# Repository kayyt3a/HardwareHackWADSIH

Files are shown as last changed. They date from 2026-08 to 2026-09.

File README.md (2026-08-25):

# Vocalens — FourSight

Hardware Hack 2026 — Challenge 1C, "Eyes for Labels"

A pair of glasses for people with low vision that read the world aloud on
request. Say the wake word and ask a question — "what does this say?",
"what colour is this?", "is this the ten or the twenty?" — and hear a short
spoken answer through a bone-conduction transducer.

Also handles:
- **Barcode/QR scanning** — checked first, before the vision model, so a
  recognised product answers near-instantly with no model call at all.
- **A per-wearer profile** (`server/profile_store.py`, set up once at
  `/setup`) — either dosage-relevant facts (age, weight, conditions,
  allergies) surfaced as context when relevant, or a voice-built reminders
  list ("remember this" / "what do I have coming up"). See
  `docs/ARCHITECTURE.md` for why these are kept as facts-only context, never
  a recommendation.

Built on a Seeed XIAO ESP32S3 Sense as a dumb sensor/actuator (camera, onboard
mic, a temple touch pad as a manual backup trigger, a bone-conduction
transducer for audio out). All intelligence lives server-side in Python,
following the same capture → server → vision-language model → action pattern
as [otto_finder](https://github.com/bethqzak/otto_finder).

## Why glasses, not handheld

Elderly users are prone to losing or forgetting to carry a separate handheld
device. Worn glasses solve that by design — nothing to remember to pick up —
and pointing your face at something is also a more natural aiming motion than
aiming a handheld unit, which directly addresses the brief's repeated point
that "aiming, not reading, is the real problem."

## Activation

Two triggers, by design (see `docs/ARCHITECTURE.md` for the reasoning):
- **Wake word** ("hey ..., what does this say?") — hands-free, the headline
  UX. Runs as local on-device keyword spotting so no audio leaves the glasses
  until it fires.
- **Touch pad on the temple** — manual backup for noisy environments or a
  wake-word miss, and what to build/test against first since the wake-word
  path depends on ESP-SR integration (see `firmware/src/wake_word.h`).

## Why a dedicated device and not just a phone

- Hands-free and always worn — nothing to find, unlock, or hold up.
- Head-aim replaces screen-aim, which matters when you can't see the screen
  to aim it in the first place.
- Silent and camera-off by default: nothing records or transmits until a
  trigger fires — an important claim to be able to make plainly in the pitch
  given a face-worn camera reads as more surveillance-adjacent than a
  handheld one.

## Repo layout

```
firmware/   PlatformIO project for the XIAO ESP32S3 Sense
server/     FastAPI server: speech-to-text + vision call + TTS
docs/       Architecture notes, pitch prep, judging-criteria checklist
```

## Quick start

**Server**
```
cd server
python -m venv .venv && source .venv/bin/activate
pip install -r requirements.txt
cp .env.example .env   # fill in ANTHROPIC_API_KEY and OPENAI_API_KEY
uvicorn main:app --host 0.0.0.0 --port 8000
```

`pyzbar` (barcode decoding) needs the system `zbar` library — `apt install
libzbar0` on Debian/Ubuntu, `brew install zbar` on macOS — install that
before `pip install -r requirements.txt` if the import fails.

Visit `http://<server-ip>:8000/setup` to set up a wearer's profile
(dosage facts or reminders mode) before a demo.

**Firmware**
```
cd firmware
cp src/secrets.h.example src/secrets.h   # fill in WiFi + server IP
pio run -t upload
```

Bring-up order: get the touch-pad trigger + camera + `/read_label` round trip
working first (no mic, no wake word needed), then layer on mic recording +
`/ask`, then wake-word detection last — it's the highest-risk piece, see
`firmware/src/wake_word.h`.

See `docs/ARCHITECTURE.md` for the full data flow and `docs/JUDGING_CHECKLIST.md`
for how this addresses the brief's dignity/privacy/failure-mode questions.

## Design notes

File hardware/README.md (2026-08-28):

# Vocalens — enclosure

**Two pods, kit parts only, zero purchases.** No FPC ribbon, no
bone-conduction transducer — nothing bought. Bone conduction stays a
documented future upgrade (see below); the two-pod split itself is achieved
with the kit's own jumper wires instead.

## What it is

Two 3D-printed pods connected by jumper wires along the temple arm — sitting
**beside** the temple arm, not stacked on top of it (see "How they sit on
the arm" below for why that distinction matters):

- **Front pod** (near the hinge): the XIAO ESP32S3 Sense with its camera
  left attached — no ribbon surgery — plus the touch pad. 48 × 10 × 29mm
  (length along the arm × vertical × outward from the head).
- **Rear pod** (behind the ear): the kit's audio amplifier and speaker.
  57 × 10 × 38mm.

Connected by 5 jumper wires (BCLK, LRC, DIN, 3V3, GND) from the kit's own
stock (65 M-M + 20 F-F + 20 F-M) — I2S is a slow serial protocol, so it
tolerates that run length without the signal-integrity risk a stretched
camera ribbon would carry.

**Honest tradeoff:** the jumper wires run exposed along the outside of the
temple arm for ~10cm. Less tidy than a hidden ribbon, and worth naming
proactively in the pitch: "jumper wires for this prototype, a custom flex
cable in a production version."

Clipping onto an existing frame rather than fabricating one from scratch
avoids the hinge/nose-bridge/lens-fit problem entirely — mounting is the
thing the challenge brief calls out as most often underestimated, and a
frame that already fits a real face solves that for free.

## How they sit on the arm — the vertical dimension is the one that matters

Both pods are deliberately **thin vertically (10mm) and long outward
(29-38mm)**, not the other way around. This isn't cosmetic — it's the
difference between a pod that clears the head and one that doesn't.

A temple arm sits right against the side of the skull. There's almost no
clearance directly above or below it before you hit hair or bone; there's
plenty of clearance straight outward, away from the head. So every
component's **thickness** (a PCB's own profile, a speaker's depth — a few
mm) is what's allowed to add to the pod's vertical extent, and every
component's **footprint** (a 28mm speaker diameter, a 19mm board width) is
what extends outward instead. Get this backwards and the pod piles up on
top of the arm and presses into the wearer's head — which is exactly what
an earlier version of this file did (front pod was 22mm vertical, rear pod
was 31mm, both several times the arm's own ~6mm width).

The front pod's camera also no longer sits stacked on top of the board —
it's positioned beside it along the arm's length instead, using the slack
in its stock ribbon. That trade costs the front pod some length (36mm →
48mm) but is what gets its vertical extent down from 22mm to 10mm — worth
it, since length runs along a part of the head with actual room, and
vertical bulk runs straight into it.

## Files

- `cad/vocalens_pod.scad` — parametric source
- `cad/split_plate.stl` — the two-pod build: both pods, both lids, fit test
- `cad/frontboard_*.stl`, `cad/rearaudio_*.stl` — the same parts separately
- `cad/single_plate.stl` — a one-pod fallback, kept for reference. Still
  bulkier vertically (23mm) than the split build, since it has nowhere to
  lay the board+camera+amp side by side without becoming very long — prefer
  the split build whenever possible.

## Print order

**1. `fit_test.stl` first, always.** Cut from `split_plate.stl` or render
alone:
```
openscad -o fit_test.stl -D 'part="fit_test"' cad/vocalens_pod.scad
```
~3 minutes. Snap it onto your actual glasses.
- Won't go on / splays the arm → increase `SNAP_GAP`, reprint
- Slides around loosely → decrease `SNAP_GAP`, reprint
- Rattles in the channel → your `TEMPLE_THICKNESS`/`TEMPLE_WIDTH` don't
  match your real glasses — measure again

Only proceed once it grips properly.

**2. Then `split_plate.stl`** — both pods, both lids, a spare fit test,
113 × 48mm, comfortably inside the Snapmaker U1's 270 × 270mm bed.

### Slicer settings (Snapmaker U1, 0.4mm nozzle)

- Layer height 0.16mm
- 4 perimeters (`WALL` is 1.6mm, sized for exactly this)
- Print bases cavity-up, as modelled — the temple channel bridges rather
  than needing supports
- Both lids in `split_plate.stl` are pre-flipped rib-side-up so they sit
  flat on the bed with no supports; if slicing a lid alone, flip it yourself
- **Material: print bases in TPU, lids in PETG.** The base is the part
  that flexes every time the pod is clipped on/off — TPU doesn't fatigue or
  crack under repeated flex the way PLA/PETG do, and it's more forgiving of
  small errors in `SNAP_GAP`. The lid doesn't flex; it just needs to hold
  its shape, so keep it rigid (PETG). This needs no CAD changes — it's a
  per-part material choice, not a geometry change. TPU needs its own
  slicer profile (slower speed, less retraction) — test on a spare small
  part first if the U1 doesn't already have one dialled in.
- Use PLA only for the disposable `fit_test.stl` iterations while tuning
  `SNAP_GAP` — fastest to print, and you'll reprint it several times

## Measure before you print

Every dimension in `vocalens_pod.scad` is a **placeholder**. Real numbers,
off your actual parts:

| Parameter | Measure |
|---|---|
| `TEMPLE_THICKNESS`, `TEMPLE_WIDTH` | The glasses you're clipping onto |
| `CAM_LEN/WID/HGT` | The camera module, still attached to its ribbon |
| `XIAO_LEN/WID` | The board's footprint |
| `XIAO_THICK` | The board's own profile (PCB + tallest onboard part, e.g. the USB connector) **excluding** the camera — this is new, and is what lets the camera sit beside the board instead of stacked on it |
| `SPKR_DIA`, `SPKR_HGT` | The kit's round speaker |
| `AMP_LEN/WID/HGT` | The kit's Audio Converter & Amplifier module |

No separate touch sensor needed: ESP32 capacitive touch runs off a bare
GPIO pad. The touch pad is a small metal disc or screw head glued into the
lid's recess and wired back to one pin.

## For the pitch: what we'd build with more time/budget

Say this plainly and proactively — it reads as scoping discipline, not as
an apology, and it directly answers the brief's "what would you do next."

| Upgrade | What it needs | What it buys |
|---|---|---|
| **Camera fully detached from the board** (rather than riding along in the front pod) | A ~10cm FPC ribbon (the camera's kit ribbon is too short to reach the rear pod) | Front pod shrinks to a camera-only footprint, and its length drops back toward ~26mm since the board no longer shares the pod at all |
| **Tidy, hidden cabling** between pods | A short length of thin sheathed cable, or a printed channel | Replaces the exposed jumper wires with something that looks intentional |
| **Bone-conduction audio** | A transducer (not stocked in Perth; not in either kit) | Rear pod's outward extent drops sharply since the speaker's 28mm footprint is replaced by a ~21mm transducer mounted flush against the head rather than sitting inside the cavity; private to the wearer; ears stay open |
| **Wake-word activation** | Firmware only (ESP-SR), no purchase | Hands-free — no tap needed at all |

We deliberately built this prototype from the provided kit with no external
sourcing, so what you're looking at tonight has zero shipping risk and zero
budget beyond what the event gave every team. Pre-rendered reference STLs
for the bone-conduction variant are in `cad/bone_conduction/` if useful for
a visual in the deck — they were not printed for this build.

## Known limitations, stated plainly

- **Jumper wires run exposed** along ~10cm of the temple arm between the
  pods. Not hidden, not strain-relieved. Say this in the pitch rather than
  let a judge notice it first — it's the direct, honest cost of a two-pod
  split with zero external sourcing.
- Both pods extend noticeably outward from the head (29-38mm) in exchange
  for staying thin vertically. That's the deliberate trade this design
  makes — see "How they sit on the arm" above — but it does mean the pods
  are visible in profile from the side, more like a small camera clipped on
  than a flush-fitting accessory.
- Corners are lightly rounded (1mm) but the overall shape is still a
  utilitarian bar, not a finished consumer product.
- The clip grips by spring tension only, from the base material itself
  (TPU is the intended material for exactly this reason — see slicer
  settings above). If a PLA/PETG-printed base still feels loose in
  practice, reprinting the base in TPU is the real fix; there isn't
  meaningful room in the channel's tolerance to add a separate liner
  without resizing it.
- No strain relief where cables exit either pod.

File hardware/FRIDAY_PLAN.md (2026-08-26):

# Friday prototype — two-day plan

**Goal:** something you can put on your face, tap, and hear it read a label.
Nothing more.

**This is the committed build, not a stopgap.** The team has decided against
any external purchases — no bone-conduction transducer, no FPC ribbon.
Two pods, connected by the kit's own jumper wires instead of a ribbon: the
XIAO+camera up front, the amp+speaker behind the ear. Bone conduction and a
tidied/hidden cable stay a "what we'd build next" slide in the pitch (see
`hardware/README.md`).

**Files:** `cad/split_plate.stl` — both pods, both lids, fit test. That's
the whole print, for Friday and for the final demo.

**Fallback if printing time runs short:** `cad/single_plate.stl` — one pod,
everything in it, no jumper-wire run to route. Same electronics, same
firmware, just one enclosure instead of two. Switching to this costs you
nothing at the firmware/server level if Thursday goes badly.

**Honest expectations.** The wires between the pods run exposed along the
temple arm — not hidden, not strain-relieved. Say this plainly in the pitch
as the direct, stated cost of a two-pod split with zero external sourcing
— that's a deliberate scope decision, not an oversight, and framed that way
it reads as discipline rather than a limitation you're hiding.

---

## Split the work — 4 people, 2 tracks in parallel

Do NOT serialise this. Tracks A and B don't touch each other until Thursday
evening.

| Track | People | Job |
|---|---|---|
| **A — Electronics** | 2 | Get camera → server → speech working on the bench |
| **B — Enclosure** | 2 | Measure, print, test-fit |

---

## WEDNESDAY

### Track A — electronics (bench only, no enclosure)

1. **Flash the XIAO, confirm the camera works.** Use any stock ESP32 camera
   example first. If you don't get an image, stop and fix that — nothing
   downstream matters.
   - PSRAM must be set to **OPI PSRAM** in board config or camera init fails.
2. **Stand up the server.** `cd server && pip install -r requirements.txt`,
   fill in `.env`, `uvicorn main:app --host 0.0.0.0 --port 8000`.
   - `pyzbar` needs the system `zbar` library — `apt install libzbar0` /
     `brew install zbar`. Do this now, not Thursday night.
   - Test it with no hardware at all: POST a photo of a label from your
     laptop to `/read_label` with curl. Confirm you get audio back. **This
     de-risks the whole AI half before hardware is involved.**
3. **Wire the amp + speaker** (jumper wires, no soldering unless the speaker
   leads need it). Use SHORT wires on the bench for now — you'll swap to
   temple-length ones once both pods exist, on Thursday:

   | Amp | XIAO | |
   |---|---|---|
   | BCLK/SCK | GPIO 7 | |
   | LRC/WS | GPIO 8 | |
   | DIN | GPIO 9 | |
   | VIN | 3V3 | |
   | GND | GND | |

   Play any fixed sound from the XIAO. Don't involve the server yet.
4. **Join them up.** Tap-to-capture → server → speech out of the speaker.
   For the touch pad, a jumper wire from **GPIO 3** to a coin or screw head.

**End of Wednesday, Track A:** a breadboard rat's nest that takes a photo
when you touch a wire and speaks the answer. Ugly. Working.

### Track B — enclosure

1. **Measure everything** with callipers (ruler is OK):
   - Temple arm thickness and width of the glasses you're using
   - The XIAO with camera attached, and the amp module, and the speaker
2. **Update those numbers** at the top of `cad/vocalens_pod.scad`.
3. **Print `fit_test` only.** ~3 minutes. Snap it on the glasses.
   - Won't go on / splays the arm → increase `SNAP_GAP`, reprint
   - Slides around → decrease `SNAP_GAP`, reprint
   - Expect 2-3 iterations. This is normal and it is cheap.
4. Once the clip grips: re-render and print `split_plate.stl` (both pods).
   ```
   openscad -o split_plate.stl -D 'part="split_plate"' cad/vocalens_pod.scad
   ```
   Running behind schedule? Print `single_plate.stl` instead — one pod, no
   jumper-wire run between pods to fuss over. Decide this by end of
   Wednesday, not Thursday night.

**End of Wednesday, Track B:** a clip that grips your glasses properly, and
pod(s) printing overnight.

---

## THURSDAY

### Track B (morning)

5. **Dry-fit the electronics into the printed pod** — no glue yet. Does the
   board go in? Does the camera line up with the lens hole? Does the lid
   close?
   - Something doesn't fit → adjust that parameter, reprint that one part.
     You have all day. This is why you dry-fit before gluing.

### Track A (morning) — hardening, not new features

6. **Run the demo ten times in a row.** Count failures. You're looking for:
   - WiFi dropping or reconnecting slowly
   - Touch pad false-triggering or missing taps (tune `TOUCH_THRESHOLD`)
   - Server timeouts
7. **Fix whatever failed.** Do not add features today.

### Both tracks (afternoon)

8. **Assemble for real.**
   - Front pod: board (camera attached) glued in, lens aligned with the
     hole; touch-pad metal glued into the lid recess and wired; USB cable
     out through the side slot
   - Rear pod: amp and speaker seated side by side, speaker under the
     grille holes
   - Swap the bench's short jumper wires for temple-length ones between the
     pods, re-test before clipping anything on
   - Press both lids on, clip both pods to the temple arm, route the wires
     along the top edge with a dot of removable adhesive
9. **Wear it. Test it. Ten more times.**

---

## FRIDAY

10. **Morning: demo rehearsal, not building.** Run the three demo beats:
    - a barcode read (fast, no model call)
    - an open question ("what does this say?")
    - a deliberate bad angle → it says it can't see clearly
11. **Take photos and video of it working.** Do this while it works. If
    something breaks Friday afternoon you still have evidence.
12. **Write down what broke this week and what you'd do next.** That's your
    "what's next / what we didn't build" pitch slide, and it's much easier to
    write now than three weeks from now.

---

## If you fall behind — cut in this order

1. **Cut the spoken question first.** Tap-to-capture with a fixed "what does
   this say?" is a complete demo. `/read_label` already does exactly this and
   needs no mic work at all.
2. **Cut on-device audio second.** Play the server's reply from the laptop
   speakers. Say so plainly in the pitch — judges accept scoping honesty.
3. **Cut the enclosure last.** Electronics gaffer-taped to glasses still
   demonstrates the idea. A beautiful empty box does not.

**Never cut:** the confidence gate that makes it say "I can't see that
clearly." That behaviour is worth more to the judges than any feature —
it is a specific thing the brief says it scores.

---

## After Friday (the remaining 3 weeks)

No purchases — the enclosure and speaker are done as of this build. Focus
shifts entirely to hardening what's built and to firmware:

- Wake word (ESP-SR) — highest risk, keep the touch pad as backup regardless
- Round the enclosure edges; the brief judges whether it looks wearable
- Reliability passes: run the demo dozens of times, fix what fails
- Battery power instead of USB tether
- Rehearse the pitch's "what we'd build next" answer — two-pod split and
  bone conduction, from `hardware/README.md` — so it's ready when asked
- Battery, so it isn't USB-tethered

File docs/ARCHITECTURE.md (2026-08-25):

# Architecture

## Data flow

```
[XIAO ESP32S3 Sense, glasses-mounted]
   trigger: wake word (local, on-device) OR temple touch-pad tap
        |
        v
   record ~4s of question audio from onboard mic
   capture JPEG frame
        |
        v  HTTP POST multipart/form-data (image + question_audio)
[FastAPI server, LAN]
        |
        v  Whisper transcription of question_audio (if present)
        v  intent classification (keyword-based, server/intent.py):
        |    "remember" -> save current read to the profile's reminders
        |    "recall"   -> read back saved reminders, no camera/model call
        |    "ask"      -> default path, continues below
        v
   [ask path] barcode/QR decode first (server/barcode.py) -- if it decodes
   AND the product is found in Open Food Facts, answer immediately, no
   model call at all
        |  (no barcode, or not found -> fall through)
        v
   one Claude vision call: image + transcribed question + optional dosage
   context from the user's profile (age/weight/conditions/allergies --
   facts only, the prompt explicitly forbids the model from turning these
   into a safety verdict, see server/vision.py)
   prompt asks for: spoken_summary, category, confidence, needs_reposition
        |
        v  if confidence low or needs_reposition: skip the model's answer,
        |  return a short "can't see that clearly, move closer" message
        v
   TTS synthesis -> MP3 bytes
        |
        v  HTTP response: JSON header + streamed MP3 body
[XIAO ESP32S3 Sense]
   play MP3 over I2S -> amp -> bone-conduction transducer
```

## Why two triggers, not just the wake word

The wake word is the headline UX ("glued to their head," hands-free,
matches how the team wants this to feel to use) but it carries real
technical risk: on-device wake-word spotting (ESP-SR WakeNet) is the hardest
integration in this build, and a demo-night miss with no fallback would
strand the whole demo. The touch pad costs almost nothing to add and means
the rest of the pipeline (camera, mic, server, TTS, playback) can be built
and fully tested well before wake-word detection is working. Build in this
order:
1. Touch pad + camera + `/read_label` (no audio question at all)
2. Touch pad + mic + `/ask` (spoken question, still manually triggered)
3. Wake word replacing/joining the touch pad as the primary trigger

## Why one model call per question, not a pipeline

Same reasoning as otto_finder: doing interpretation + response-shaping in one
Claude vision call (given the transcribed question as context) is simpler to
reason about and cheaper to build in a hackathon timeframe than chaining
multiple models. Speech-to-text is a separate call because Claude's messages
API doesn't take raw audio input directly — Whisper handles that step, then
the transcribed text goes into the same vision call as before. (otto_finder
avoided this by using Gemini via OpenRouter, which accepts audio and image in
a single multimodal call — worth considering as a later optimisation if
reducing to one round-trip matters more than sticking with Anthropic's
vision credits; see `server/vision.py` for the swap point.)

## Latency budget

Trigger → spoken answer, target under ~5-6s (a bit more headroom than a
handheld device since there's a transcription step in the chain now):
- Mic recording: ~2-4s, fixed by how long the person takes to ask
- JPEG capture + WiFi upload: ~200-500ms on local WiFi at VGA resolution
- Whisper transcription: ~0.5-1.5s
- Claude vision call: ~1-3s (dominant network cost — keep the prompt short)
- TTS synthesis + playback start: ~0.5-1s, streamed so playback starts
  before the full file arrives

## Offline behaviour

If the server is unreachable, the firmware falls back to on-device
barcode/QR decode and speaks a locally-stored "no internet, can't look that
up right now" message rather than hanging silently. See
`firmware/src/offline_fallback.h`. Speech-to-text and TTS both need network
in the current config (OpenAI-backed), so the offline path skips the
question entirely rather than attempting a degraded version of it.

## User profile: dosage facts vs. reminders

`server/profile_store.py` holds one JSON record per wearer, set up once via
the bench-only form at `/setup` (see `server/static/profile_setup.html`) —
this is a setup tool, not part of the wearable's own interaction loop.

Two `profile_type` modes, matching the two personas discussed for this
build:
- **"dosage"** — age, weight, known conditions, known allergies. Only ever
  fed to the model as context to *surface* a printed detail the person
  might care about ("this contains X, which you've listed as an allergy").
  The system prompt explicitly forbids turning this into a recommendation
  or safety judgment — this device is not a medical device (see the
  brief's ethics section), and a dosage *verdict* is 1B's territory, not
  1C's.
- **"reminders"** — a plain list the wearer builds themselves by saying
  "remember this" after a read (e.g. pointing at an event flyer or
  appointment card). Recalled by asking "what do I have coming up" — pure
  text-to-speech from stored strings, no camera or model call needed for
  recall itself. This is deliberately NOT a synced calendar; it's exactly
  as much memory as the wearer explicitly asked the device to keep.

Only one profile type should be set per device for a given demo — the
dosage/reminders split exists because these are two different user
personas (the brief's "80-year-old managing nine medications" vs. a
younger low-vision user with a normal social calendar), not because a
single wearer needs both at once.

## Privacy

- Camera and mic only capture on a trigger (wake word or touch pad). No
  continuous recording or streaming — the local wake-word model only ever
  produces a yes/no keyword match, it does not itself transmit audio.
- Nothing is sent anywhere except the local server on the user's own network.
- State this plainly in the demo pitch — a face-worn camera reads as more
  surveillance-adjacent to an onlooker than a handheld one, so this claim
  needs to be made clearly and be visibly true (e.g. a small LED that lights
  only while actively capturing is worth considering as a trust signal).

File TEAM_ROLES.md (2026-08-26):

# FourSight — who owns what

Four people, four owned areas. The point of the split is that **nobody is
ever blocked waiting on someone else**, and every part of the product has
exactly one person whose name is on it.

Assign the letters to real names at your first standup and put them at the
top of this file.

| | Role | Owns | The thing they must not let fail |
|---|---|---|---|
| **A** | Firmware | The device | The board captures and speaks on demand |
| **B** | Server / AI | The intelligence | The answer is right, or honestly says it isn't |
| **C** | Hardware | The physical thing | It fits on a face and stays there |
| **D** | Demo & pitch | The story | It works live, and the pitch answers the brief |

---

## A — Firmware owner

**Owns:** `firmware/`, the XIAO, everything that runs on the device.

- **Week 1:** camera capture working, tap-to-trigger on GPIO 3, I2S audio out
  through the amp and speaker. Photo posts to B's server and the reply plays.
- **Week 2:** mic recording on long-press, spoken question uploaded alongside
  the photo. Tune `TOUCH_THRESHOLD` so it doesn't false-trigger.
- **Week 3:** wake word (ESP-SR). **This is the highest-risk item in the whole
  project.** Timebox it. If it isn't working by end of week 3, ship the touch
  pad and say so in the pitch — that is a perfectly good outcome.
- **Week 4:** battery power instead of USB tether. Reliability passes.

**Done means:** trigger → photo + audio uploaded → reply plays, ten times in
a row without a failure.

**Watch out for:** PSRAM must be set to OPI PSRAM or the camera won't init.
Don't start on the wake word until everything else is solid.

---

## B — Server / AI owner

**Owns:** `server/`, the vision prompt, the API keys and cost.

- **Week 1:** server running, `/read_label` answering correctly from photos
  curl'd off a laptop. **Do this before A has working hardware** — it de-risks
  the entire AI half independently.
- **Week 2:** `/ask` with Whisper transcription; barcode fast-path verified
  against real products; tune the confidence threshold.
- **Week 3:** profile modes (dosage facts / reminders). Test the prompt
  refuses to give medical advice — a judge will probe this.
- **Week 4:** latency tuning, graceful failure when WiFi or the API drops.

**Done means:** given a bad photo it says "I can't see that clearly" instead
of guessing. Given a good one it answers in under ~5 seconds.

**Watch out for:** `pyzbar` needs the system `zbar` library installed. Keep
an eye on API credit burn from day one.

---

## C — Hardware owner

**Owns:** `hardware/`, the CAD, the printer, assembly, how it looks.

**Committed build: two pods, kit parts only, zero purchases.** Board+camera
up front, amp+speaker behind the ear, connected by the kit's own jumper
wires instead of a bought FPC ribbon. Bone conduction and a hidden/tidied
cable are pitch material (`hardware/README.md`), not something being built
this event — don't spend week 2/3 time on them.

- **Week 1:** measure everything, update the `.scad` parameters, iterate
  `fit_test` until the clip grips properly, print and dry-fit both pods.
- **Week 2:** cable routing and strain relief for the jumper-wire run
  between pods; fix whatever the dry-fit revealed.
- **Week 3:** make it look like something a person would wear — round the
  edges, tidy the seams, sensible filament colour. **The brief explicitly
  judges this.**
- **Week 4:** final assembly, plus a spare printed set in case something
  cracks on demo day.

**Done means:** someone can wear it for ten minutes without it sliding off or
annoying them.

**Watch out for:** book printer slots early — the brief says printing is the
most common cause of a demo-night scramble. Since it's front-heavy by
design (kit speaker + board + camera all up front), test wear-comfort early
rather than discovering it demo week.

---

## D — Demo & pitch owner

**Owns:** the deck, the persona, demo-night execution, and — most
importantly — **integration testing**.

This is not the "non-technical" job. D is the only person testing the whole
system as a user would, which is the only test that predicts demo night.

- **Week 1:** build out the Margaret persona properly. Talk to mentors about
  how people with low vision actually organise a pantry. Collect the props
  you'll demo with (medication boxes, similar-looking bottles, a barcoded
  item, something handwritten).
- **Week 2:** start end-to-end testing whatever A, B and C have. Log every
  failure and hand it to whoever owns it. Draft the deck.
- **Week 3:** rehearse the three demo beats — barcode read, open question,
  deliberate failure. Time the pitch. Prepare answers to the brief's dignity
  questions: who's in control, what does it collect, what happens when it's
  wrong, what does it cost.
- **Week 4:** rehearse daily. Own the demo-night run sheet and the backup
  plan.

**Done means:** the demo runs three times in a row without surprises, and the
pitch is under time.

**Watch out for:** don't let this role drift into "just does slides." The
integration testing is the valuable half.

---

## Where the tracks meet

Everything else runs in parallel; these are the only hard dependencies.

| When | Handoff |
|---|---|
| **End week 1** | A's device talks to B's server. First real end-to-end. |
| **Mid week 2** | C's printed pod holds A's electronics. Dry-fit before gluing. |
| **End week 2** | D starts testing the assembled system daily. |
| **End week 3** | Feature freeze. Nothing new after this — only fixes. |
| **Week 4** | Everyone rehearses. |

**Feature freeze at end of week 3 is the most important line in this
document.** Teams lose hackathons by adding a feature on the last day and
breaking the thing that worked.

---

## Cross-training (do this, it's cheap insurance)

By end of week 2, at least two people should be able to:
- Flash the firmware
- Start the server and check its logs
- Slice and start a print

One person getting sick in week 4 should not end your project.

---

## Standups

Ten minutes, same time daily. Three questions each:
1. What's working now that wasn't yesterday?
2. What's blocking you?
3. What do you need from someone else in this room?

If an answer to (3) exists, resolve it in the room. Don't leave it for later.

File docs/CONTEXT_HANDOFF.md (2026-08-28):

# Vocalens — full project context (handoff prompt)

> Paste everything below this line into ChatGPT (or any other assistant) as your
> first message. It is written to be self-contained: it assumes the reader has
> never seen this project.

---

You are helping my four-person team plan and build a hardware/AI project for a
hackathon. Read this entire brief before responding. At the end I'll tell you
what I want help with. Ask me clarifying questions if something is genuinely
ambiguous, but don't re-litigate decisions marked as **locked**.

## The event

- **Hardware Hack 2026**, hosted by WADSIH (WA Data Science Innovation Hub) at
  Innovation Central Perth, Curtin University.
- Team name: **FourSight** — 4 members, ~4 weeks including workshops.
- We are entering **Challenge 1C — "Eyes for Labels"**: assistive technology
  for people with low vision reading labels and packaging.
- There is also an OpenRouter-sponsored track, so LLM API usage is encouraged.
- Final demo slot is **~3 minutes**, plus judged pitch.

### Constraints from the challenge brief (these are hard rules)

1. "Do not use anybody's real medical or medication information in your
   prototype. **Use synthetic data and your own team as test users.**"
2. "Your prototype is **not a medical device**. Do not make clinical claims."
3. "Language matters in your pitch — describe what the device does and who it
   is for; **avoid framing people as problems to be managed**."
4. The brief specifically warns that **mounting/physical attachment** is the
   thing teams most often underestimate.
5. The brief judges **whether it looks like something a person would wear**.

## The product: Vocalens

**Three-sentence version:** Vocalens is a pair of clip-on pods that attach to
glasses you already own. You tap your temple (or eventually say a wake word),
it photographs whatever you're looking at, and a vision-language model reads it
back to you through a small speaker behind your ear. It also scans barcodes,
reads expiry dates and dosage labels, and remembers a small amount of
personal information you tell it, so answers are tailored to you.

**Why glasses, not a handheld** (locked decision): elderly users lose handheld
devices constantly. Glasses are already glued to their head. The whole product
thesis is *the device is where their eyes already are*.

**Architecture** (borrowed from an existing project called `otto_finder`):
dumb board, server-side intelligence. Camera → WiFi → server → VLM → audio
back. The ESP32 does almost no thinking.

## Hardware — what we actually have

**Locked constraint: ZERO external purchases.** Everything is built from:

- **Seeed XIAO ESP32S3 Sense** — camera, PDM mic, WiFi/BLE, PSRAM
- **Freenove Ultimate Starter Kit** — which importantly contains a **Speaker**
  and an **Audio Converter & Amplifier** module, plus jumper wires (65 M-M,
  20 F-F, 20 F-M), battery holders, etc.
- A **Snapmaker U1** 3D printer — 270×270×270mm FDM, multi-material (4 spools).
  Available filaments: **PLA, PETG, TPU**.
- An ordinary pair of glasses to clip onto.

Things we deliberately did NOT buy and instead demoted to "what we'd build
next" pitch material: a bone-conduction transducer, a longer FPC camera ribbon,
sheathed/hidden cabling.

### Physical design (already CAD'd, validated, and printing)

Two pods connected by 5 jumper wires (I2S: BCLK, LRC, DIN, 3V3, GND) running
~10cm along the temple arm. I2S is slow serial, so jumper wires are
electrically fine at that length — this is how we got a two-pod split without
buying a ribbon.

- **Front pod** (near hinge): XIAO + camera (camera stays on its stock ribbon,
  positioned *beside* the board rather than stacked on it) + capacitive touch
  pad. 48 × 10 × 29 mm.
- **Rear pod** (behind ear): audio amp + speaker. 57 × 10 × 38 mm.

**The single most important geometry insight**, learned the hard way after a
failed first design:

> A temple arm sits right against the skull. There is almost **no clearance
> above or below** it before you hit hair or bone. There is **plenty of
> clearance straight outward**, away from the head. So a component's
> **thickness** (PCB profile, speaker depth — a few mm) is what may add to the
> pod's **vertical** extent, and a component's **footprint** (28mm speaker
> diameter, 19mm board width) must extend **outward** instead.

Getting this backwards made the pods 22mm and 31mm tall and they pressed into
the wearer's head. Fixing it brought both to ~10mm vertical. The CAD source
(`hardware/cad/vocalens_pod.scad`, OpenSCAD, fully parametric) documents the
axis convention in a comment block at the top:

```
X (length)  — along the temple arm, front to back.
Y (BODY_W)  — the arm's TOP-TO-BOTTOM axis. KEEP SMALL. Pass THICKNESS here.
Z (cav_h)   — straight out away from the head. Real clearance. Pass FOOTPRINT here.
```

Materials decision: **bases in TPU** (the base is what flexes on every
clip-on/off — TPU doesn't fatigue-crack and forgives errors in the snap-fit
tolerance), **lids in PETG** (rigid, doesn't flex), **PLA for disposable
fit-test iterations**. The clip grips by spring tension only; a `SNAP_GAP`
parameter is tuned by printing a ~3-minute `fit_test.stl` repeatedly.

All STLs verified watertight/manifold using `trimesh` (`is_watertight`), after
a homemade edge-counting checker gave false positives. Note: **OpenSCAD
silently evaluates unknown variables as `undef` without erroring**, which once
produced genuinely broken plate STLs after a variable rename.

### Known rough edges (we state these openly in the pitch)

- Jumper wires run **exposed** along ~10cm of the temple arm. Not hidden, not
  strain-relieved.
- Pods extend visibly outward (29–38mm) — the deliberate trade for staying thin
  vertically. Looks like a small clipped-on camera, not a flush accessory.
- Utilitarian bar shape with only 1mm corner rounding.
- No strain relief where cables exit.

## Software — what exists

### `server/` (Python, FastAPI) — complete and syntax-verified

- **`main.py`** — endpoints:
  - `POST /ask` — image + optional `question_audio` + `user_id` form field.
    Flow: transcribe → classify intent → recall / remember / ask → barcode
    fast path → vision call → TTS.
  - `POST /read_label` — no-audio bench path for testing with `curl`.
  - `GET /health`, `GET|POST /profile/{user_id}`
  - `/setup` — serves a static HTML profile-setup page.
- **`vision.py`** — Claude vision (`claude-sonnet-5`). System prompt returns
  JSON `{spoken_summary, category, confidence, needs_reposition}` and
  **explicitly forbids medical verdicts**.
- **`profile_store.py`** — JSON-backed per-user profiles. Two modes via
  `profile_type`: `"dosage"` (age, weight, allergies) and `"reminders"`
  (saved events). **Critical design point:** `dosage_context_summary()`
  returns `None` unless `profile_type == "dosage"` — health facts are never
  *assembled* in reminders mode, not merely filtered later.
- **`intent.py`** — trigger phrases: remember = `["remember this",
  "remember that", "save this", "add this"]`; recall = `["what do i have",
  "what's coming up", "what did i save", "what have i saved",
  "read my reminders", "what's on my list"]`.
- **`barcode.py`** — `pyzbar` + **Open Food Facts** lookup as a fast path
  *before* spending a VLM call. (Needs the system `zbar` library installed.)
- **`stt.py`** — Whisper. **`tts.py`** — OpenAI TTS.

### `firmware/` (PlatformIO, C++)

`main.cpp` (trigger → record → capture → multipart POST to `/ask` → play MP3),
`pins.h` (touch pad GPIO 3, I2S BCLK 7 / LRC 8 / DIN 9), plus **stubs**:
`wake_word.h` (ESP-SR / WakeNet — the highest-risk item in the project),
`mic_capture.h`, `offline_fallback.h`. `audio_playback.cpp` has a TODO for the
LittleFS path.

Gotcha: PSRAM must be set to **OPI PSRAM** or the camera won't init.

### Bring-up order (deliberately staged so nothing is debugged at 2am)

1. Camera only, on the bench → confirm server receives a frame
2. Audio out, short wires → confirm reply plays
3. Extend to full temple-length wires, clip on, retest
4. Mic in → confirm transcription
5. **Wake word last** — touch pad already gives a working demo without it

## The two personas (for the pitch)

**Margaret, 78 — synthetic, the demo persona. `profile_type = "dosage"`.**
Bayswater, 31 years in the same house, retired primary school teacher, does the
crossword with a lit magnifier, hosts book club. Age-related macular
degeneration for six years — central vision largely gone, peripheral intact, so
she navigates her home confidently but can't read anything she looks directly
at. Nine daily medications, kept in a self-invented order on the windowsill,
rechecked by position. Two bottles are the same size and shape; **she has a
rubber band round one of them.**

> The key pitch line: *"The baseline isn't nothing. It's a rubber band round a
> pill bottle."* — a system she invented, maintains, and which fails silently
> the moment someone tidies the windowsill.

Her question for us: *"What happens when it gets it wrong?"* — she can't check
the answer. This is why a confidence gate exists and why we deliberately demo
a failure.

**Ethan — a REAL teammate, the second configuration. `profile_type =
"reminders"`.** CS student, commutes by train, phone constantly in hand,
entirely tech-fluent.

> **Ethical constraint (locked):** do NOT attribute low vision to him as fact.
> The honest framing, which is also the *stronger* one:
> *"Ethan's on our team — CS student, commutes in, lives on his phone. He
> doesn't have low vision. But when we asked what a younger user would need
> from this, he's who we designed around, and he's the one who's actually been
> wearing it."*

His value is that he's the **hardest** user, not the most sympathetic: a
tech-fluent 20-something who'd say it's pointless if his phone already did it.
His moment: on the train, standing, coffee in one hand, a poster he'd never
unlock his phone for — he taps his temple instead. His question: *"Why would I
use this instead of my phone?"* Answer: hands-free, no unlock, no app, same
device that already does his reading.

Pitch guidance: lead with Margaret, bring in Ethan on one late slide, **do not
demo both live** (doubles setup and doubles what can break in 3 minutes).

## The pitch deck (8 slides, built with pptxgenjs)

Title → Margaret + stat → One device two people → Meta rebuttal → LIVE DEMO →
How it works → Dignity + cost → What's next. Palette: navy `0B4F6C`, teal
`137A7F`, amber `F2A65A`.

**The Meta Ray-Ban rebuttal** (a judge will ask this): *"Why would you buy Meta
glasses for $750 when you could spend under $100?"* Plus: they're a general
consumer device with assistive features bolted on; this is built around the
dosage/expiry use case, stores per-user context, runs on frames the user
already owns and already fits their face, and deliberately refuses to give
medical verdicts.

## Team split (4 people, `TEAM_ROLES.md`)

- **A — Firmware:** the board captures and speaks on demand. Wake word is
  timeboxed to week 3; if it isn't working, ship the touch pad and say so.
- **B — Server/AI:** the answer is right, or honestly says it isn't. Gets
  `/read_label` working from curl'd photos in week 1, *before* A has hardware —
  this de-risks the whole AI half independently.
- **C — Hardware:** it fits on a face and stays there. Owns CAD, printer,
  assembly, and how it looks (the brief judges this).
- **D — Demo & pitch:** owns the deck, the persona, and — most importantly —
  **integration testing**. This is not the "non-technical" role; D is the only
  person testing the whole system as a user would.

**Feature freeze at end of week 3** is the most important line in the plan.

## Where we are right now

Done: full CAD (validated, watertight), full server code, firmware skeleton
with stubs, 8-slide deck, personas doc, team roles doc, build guide.

In progress / next: print `fit_test.stl` → tune `SNAP_GAP` → print bases (TPU)
and lids (PETG); flash the XIAO; stand up the server; wire amp + speaker;
verify the no-medical-advice guardrail with a fake `dosage` profile.

Remaining risk list, in order: **wake word (ESP-SR)** > latency under venue
WiFi > snap-fit tolerance on real glasses > demo-night reliability.

---

## What I want from you

[REPLACE THIS SECTION with your actual ask, e.g.:]

- Stress-test the pitch narrative and tell me what a judge will attack.
- Help me plan weeks 2–4 in detail.
- Suggest what to do about the wake word if ESP-SR doesn't work.
- Poke holes in the enclosure design.

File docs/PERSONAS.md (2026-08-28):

# Vocalens — the two people we built this for

Two personas, one device, two configurations (`profile_type` in
`server/profile_store.py`). Same hardware, same firmware, same pipeline —
what changes is what the device remembers and how it uses it.

**Margaret is a synthetic persona**, built from the challenge brief's own
descriptions and published research (Vision Australia, APH ConnectCenter,
National Eye Health Survey). **Ethan is a real teammate** — see the framing
note in his section, which matters.

We did not interview or test on anyone with disability — the brief is
explicit about consent and about using synthetic data, and we used
ourselves as test users as it suggests. Say this plainly if asked: it's a
limitation, not something to hide, and "we'd validate with real users next"
is the honest next step.

A note on language, straight from the brief: *"Describe what the device does
and who it is for; avoid framing people as problems to be managed."* Both
briefs below are written as people with lives, not as lists of deficits.
Keep that framing in the pitch.

---

## Margaret, 78 — the demo persona

**`profile_type = "dosage"`**

### Who she is

Margaret has lived in the same Bayswater house for thirty-one years. She
still drives to the shops in daylight, does the crossword with a lit
magnifier, and hosts her book club on the first Tuesday of the month. She
was a primary school teacher for twenty-six years and is not remotely
intimidated by technology — she just can't read it any more.

She has age-related macular degeneration, diagnosed six years ago. Central
vision is largely gone; her peripheral vision still works, which means she
navigates her own home confidently and can spot someone waving from across
a room, but she cannot read anything she looks directly at.

She manages nine medications daily.

### Her actual Tuesday

7:15am. Morning tablets. She keeps them in a specific order on the
windowsill — an order she built herself and rechecks by position, not by
reading. Two of the bottles are the same size and shape. She has a rubber
band round one of them.

**That rubber band is the thing to say out loud in the pitch.** The baseline
we're replacing isn't "nothing." It's a system she invented herself,
maintains herself, and which fails silently the moment someone tidies the
windowsill or the pharmacy changes a bottle.

11am. Her daughter drops off shopping. Margaret can't check the use-by
dates, so she either asks — which she hates doing, and does less often than
she should — or she doesn't check.

4pm. A new prescription arrives. The dispensing label is 8-point type.

### What she needs from a device

Not a reading machine. She needs *one specific fact, right now*: which
bottle is this, what's the date, is this the shampoo or the conditioner.
She needs it without asking another person, because the asking is the part
that costs her something.

### Why the dosage profile matters for her

Her profile holds her age, weight, and — the demo-relevant part — her
allergies. When she points at a box, Vocalens reads it *and* flags that it
contains something she's listed. It does **not** tell her whether to take
it. That distinction is the whole design:

> "It surfaces what's printed on the box. It never gives her a verdict.
> Margaret decides, or her pharmacist does — this device is not in that
> loop, and we built it deliberately so it can't be."

### Her question for us

*"What happens when it gets it wrong?"* — She's not asking rhetorically.
She can't check its answer. This is why the confidence gate exists, and why
the deliberate-failure beat is in the demo.

---

## Ethan — the second configuration

**`profile_type = "reminders"`**

### An honest framing note — read this before you write the slide

Ethan is a real person on your team, not an invention. That's a strength:
the brief explicitly says *"use synthetic data and your own team as test
users,"* and "he's worn it for three weeks" is worth more than any
invented backstory.

**But do not attribute low vision to him as if it were fact.** Naming a
real teammate on stage and giving him a condition he doesn't have is the
kind of thing that, once a judge realises it, costs you credibility on
everything else you said. The fix is simple and makes the pitch *better*:

> "Ethan's on our team — computer science, commutes in from [suburb], lives
> on his phone. He doesn't have low vision. But when we asked what a
> *younger* user would need from this, he's who we designed around, and
> he's the one who's actually been wearing it."

Real person, real daily routine, hypothetical clearly labelled. That's both
honest and more concrete than a fabricated character.

### Who he is

A computer science student in Perth. Commutes by train. Works with a laptop
all day, phone constantly in hand, entirely comfortable with technology —
he'd be the first person to tell you a device is pointless if his phone
already does it.

**Ethan is the harder pitch, and that's exactly why he's useful.** He is not
someone for whom "assistive technology" is a novelty. If a younger,
tech-fluent user wouldn't choose this over the phone already in their
pocket, the device has no younger market — and the brief specifically asks
you to name your answer to that.

If Ethan were losing central vision — the same thing happening to Margaret,
fifty years earlier — nothing about his day would slow down to accommodate
it. That's the design problem.

### His actual Thursday

8:10am. On the train, standing, one hand on the rail, coffee in the other.
A poster for something on at the Cultural Centre. He'd have to put the
coffee down, get his phone out, unlock it, open an app, and aim — by which
point his stop is coming up. He doesn't bother. **This is the moment the
device wins:** hands full, standing, moving, and he just taps his temple.

12:30pm. A friend mentions drinks Friday at a place he doesn't know. He'd
normally type it into his phone. With Vocalens he says *"remember this"*
and keeps eating.

6pm. Walking to the station: *"what do I have coming up."* It reads back
what he saved. Nothing was typed. Nothing synced from anyone's calendar. It
only knows what he told it.

### Why the reminders profile matters for him

He's not managing a health condition — he's managing a life. So his profile
holds **nothing medical at all**, and this is a real engineering decision,
not a marketing line:

> `dosage_context_summary()` returns `None` unless the profile is in dosage
> mode. In Ethan's configuration, health facts aren't filtered out
> downstream — they're never assembled in the first place. There is no
> health data in his device to leak, because the code path that would build
> it never runs.

### His question for us

*"Why would I use this instead of my phone?"* — Answer it directly, don't
dodge: hands-free, no unlock, no app, and it's the same device that already
does his reading, so it isn't one more thing to carry or one more app to
remember.

---

## How to use these in the pitch

**Lead with Margaret.** She's the demo persona, she's the brief's central
cohort ("older Western Australians"), and the dosage read is the more
striking live demo.

**Bring in Ethan on one slide, late** — probably alongside "what's next" or
the two-modes explanation. His job is to show the device isn't a
single-purpose gadget for one narrow group, and to prove you've tested the
"why not a phone" objection against your *most* skeptical possible user
rather than your most sympathetic one.

**Have Ethan say his own line, if he's presenting.** "I've worn this for
three weeks" lands very differently coming from the person who wore it.

**Do not demo both live.** One configuration, set up properly, demoed
cleanly. Ethan's mode is explained, not performed — it doubles your setup
and doubles what can break in a three-minute slot.

### Lines worth having ready

- *"The baseline isn't nothing. It's a rubber band round a pill bottle."*
- *"It surfaces what's printed. It never gives a verdict."*
- *"In Ethan's configuration there's no health data to leak, because the
  code that would assemble it never runs."*
- *"Margaret can't check its answer. That's why it has to be able to say it
  doesn't know."*

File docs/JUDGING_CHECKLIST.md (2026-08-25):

# Judging criteria checklist (from the challenge brief)

Fill this in as the build progresses — it's what you'll actually say on demo night.

- **Persona**: Margaret, 78, macular degeneration. Describe her actual day —
  what specific labels trip her up (medication vs. supplement bottles that
  look identical, use-by dates, shampoo vs conditioner) — and why a worn
  device beats a handheld one for her specifically (loses/forgets handheld
  items; glasses are already a habit she has if she's low-vision).
- **Who is in control?**: Device only answers when triggered (wake word or
  temple touch) and only to the wearer, through a bone-conduction transducer
  rather than a speaker — no one else in the room hears the answer. No
  autonomous escalation, no third party notified, ever — this device has no
  concept of a carer.
- **What does it look like sitting on a kitchen bench / worn at a friend's
  visit?**: Design goal — should read as ordinary glasses, not medical
  equipment. TODO: 3D-print a frame/temple housing that keeps the camera and
  electronics as unobtrusive as possible.
- **What does it do when it's wrong?**: Server returns `needs_reposition` and
  a confidence score; below threshold, device says it can't see clearly and
  asks the wearer to move or turn their head, instead of guessing. Never
  state a low-confidence read as fact.
- **Does it collect more than it needs?**: Camera and mic only capture on an
  explicit trigger (wake word match or touch pad). No continuous recording,
  no storage beyond a single request. This needs to be stated very plainly
  in the pitch — a face-worn always-available camera reads as more
  surveillance-adjacent than a handheld one to an onlooker, so the "off by
  default" claim has to be visibly true, not just asserted (consider a
  capture-indicator LED as a trust signal).
- **Could the person set it up themselves?**: TODO — decide WiFi provisioning
  approach (e.g. BLE provisioning or a captive portal) so setup doesn't
  permanently require a technical third party.
- **What does it cost?**: TODO — itemise: XIAO ESP32S3 Sense (~$20-25 USD),
  bone-conduction transducer + small amp, touch pad, battery, frame/enclosure
  fabrication. Target a bill of materials under $40-50. Wake-word hardware
  itself is free (on-device, no extra chip) but factor in dev time.
- **What's next / what did you deliberately not build?**: e.g. deliberately
  not building carer notifications or location tracking, not building
  multi-language support yet, deliberately shipped with a manual touch-pad
  trigger as backup while the custom wake word was still in training.
- **Is the profile feature a medical device claim?**: No — be ready to say
  this precisely. The dosage profile only ever surfaces a printed detail
  ("this contains X, which you've listed as an allergy"); it never says
  "safe" or "unsafe," never recommends a dose, and is not a substitute for
  a pharmacist. Say this plainly if a judge asks, don't wait to be asked.
- **Who can see/hear the reminders list?**: Playback is through a
  bone-conduction transducer the wearer alone hears — a reminder someone
  saved ("my GP appointment is Tuesday") isn't broadcast to a room the way
  a phone's speaker or screen would be. Worth naming as a deliberate
  privacy choice in the pitch.

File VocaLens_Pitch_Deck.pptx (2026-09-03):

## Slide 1

VocaLens

Glasses that read the world aloud.

Team FourSight · Hardware Hack 2026 · Challenge 1C — Eyes for Labels

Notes: Open by naming her, not the technology. 'This is Margaret.' Then the rubber band line on the next slide.

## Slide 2

This is Margaret.

78 years old. Macular degeneration. Nine medications a day.

60%

of people with vision loss struggle to locate or identify their own medication

Her question for us: “What happens when it gets it wrong?”

Source: APH ConnectCenter — medication management for blind & low vision

She keeps her tablets in an order she invented, on the windowsill, and rechecks them by position — not by reading.
Two of the bottles are the same size and shape.
So she has a rubber band round one of them.

“The baseline isn’t nothing.
It’s a rubber band round a pill bottle.”

64%

report missing doses

33%

report inaccurate dosing or spilling

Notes: The rubber band is the line to land. It is a system she invented and maintains, and it fails silently the moment someone tidies the windowsill. Her question is why we built a confidence gate and why beat 3 of the demo exists.

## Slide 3

She is not alone

Glasses and surgery cannot fully correct many of these conditions.
This is not a shrinking problem.

400,000

Cataracts

in Australia

400,000

Diabetic retinopathy

200,000

Macular degeneration

160,000

Glaucoma

Source: AIHW eye health report

Sixteen of the thirty people in this room are wearing glasses. That is not our statistic — it is our mounting bracket. VocaLens clips onto what you already own.

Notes: Count the glasses in the room before you present and update the number. Do NOT say 'half of you could end up like Margaret' — glasses mean your vision IS correctable, which contradicts this slide. The honest version is the one on the slide: they already accepted a device on their face, and it is the platform we clip onto.

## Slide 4

VocaLens

A lightweight add-on to glasses you already own.

PRODUCT PHOTO

Replace with the pods clipped onto real glasses, worn.

1

Reads text aloud

Point your face at a label and ask. The answer comes back as speech.

2

Scans barcodes

Recognised products answer instantly, with no model call at all.

3

One button

No app, no unlock, no aiming a screen you cannot see.

4

Comfortable and resilient

Two thin pods that clip on and off. Nothing glued to the frame.

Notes: PLACEHOLDER — swap in the photo of the assembled device on a face before demo day. A worn shot beats a bench shot.

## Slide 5

“Isn’t this just a cheap Meta glasses knockoff?”

$800–900

Meta glasses

A phone strapped to your face. Notifications, social media, a dozen features an elderly or low-vision user will never touch — and may never even discover.

under $100

VocaLens

One job, done reliably.
Every feature gets used — we included only what earns its place.
Head-aim replaces screen-aim: no aiming a screen you can’t see.
Clips onto the glasses already on your face.

Bone-conduction audio keeps answers private to the wearer — that is the production design. This prototype uses a small speaker, built entirely from the kit we were given.

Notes: Say the speaker swap out loud before a judge spots it. Framing it as a deliberate zero-purchase constraint reads as discipline, not compromise.

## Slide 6

LIVE DEMO

A barcode read

1

The third one matters most.

Margaret cannot check the answer herself. A device that admits uncertainty is worth more to her than one that is usually right.

Instant. Zero model calls.

An open question

2

“What does this say?”

3

A deliberate failure

It says “I can’t see that clearly” instead of guessing.

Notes: Rehearse beat 3 — do not hope it happens. Have a deliberately bad image ready: too close, too dark, or badly angled.

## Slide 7

How it works

Glasses

Camera and mic capture on trigger — never continuously.

1

Server

One round trip over the local network. Nothing leaves the room.

2

Fast path

Barcode decode first: free, instant, no model call.

3

Speak

The model runs only when needed, then text-to-speech.

4

→

→

→

A recognised barcode answers with zero model calls. The vision model runs only for the genuinely open-ended questions — a label, a colour, a comparison — that actually need it.

AI earns its place

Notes: Worth saying explicitly in a room where most projects call a model for everything. This is a design argument, not a cost saving.

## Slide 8

Designed with dignity

Who’s in control

Only the wearer hears the answer. No escalation, no third party notified, ever.

Collects only what’s needed

Capture happens on trigger. No continuous recording, nothing stored beyond one request.

under

$100

per unit in parts

XIAO ESP32S3 Sense · camera · amplifier and speaker · trigger · battery · two printed pods that clip to glasses the wearer already owns

Looks ordinary

Reads as glasses, not medical equipment, at a friend’s kitchen bench.

Not a medical device

Surfaces printed facts. Never a safety verdict, never a recommendation.

Built entirely from the kit every team was given. No external purchases, so nothing here depended on a delivery arriving.

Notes: Cost list now matches what was actually built — speaker rather than bone-conduction transducer, clip-on pods rather than a printed frame. Slide 5 already concedes the speaker, so these no longer contradict.

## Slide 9

What we deliberately didn’t build

Scope we chose, not scope we missed.

Carer notifications or location tracking

The wearer is the only person in the loop. That is the point, not an omission.

—

It surfaces what is printed.
It never gives a verdict.

—

A synced calendar

Reminders are built by the wearer, on purpose. Nothing arrives from anyone else.

—

Multi-language support

Next on the list — and the clearest next step we would take.

VocaLens

Team FourSight — thank you

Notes: Close on the verdict line. It answers the dignity question and the medical-device question at the same time.

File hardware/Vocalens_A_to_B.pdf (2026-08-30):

# A to B

38 steps. Nothing installed, nothing assumed.

What you're about to do. Install two free programs. Put the code on your laptop. Plug the board in with a USB cable. Send a test program to the board. Read what it says. Then start the AI part and watch the whole thing work.

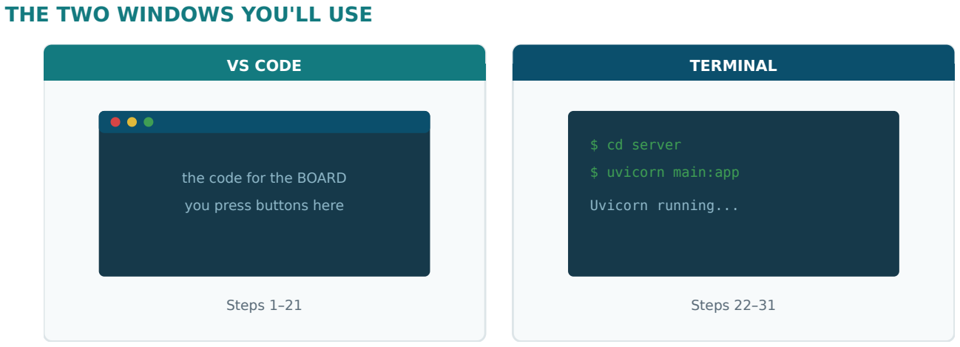
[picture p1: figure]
THE TWO WINDOWS YOU'LL USE; VS CODE; the code for the BOARD; you press buttons here; Steps 1–21; TERMINAL; $ cd server; $ uvicorn main:app; Uvicorn running...; Steps 22–31

Steps | What happens
1–6 | Install VS Code and PlatformIO
7–10 | Get the project onto your laptop
11–14 | Plug the board in and prove the laptop sees it
15–21 | Send the self-test to the board and read the results
22–31 | Start the AI server on your laptop
32–38 | Connect the two and watch it work

"Terminal" is just a window where you type commands instead of clicking. Step 22 shows you how to open one. Nothing you type there can break your laptop.

V O C A L E N S · F R O M N O T H I N G

A to B | Cover

## PART 1 — Install the software

1 Go to code.visualstudio.com and download VS Code.
It's free. It's a text editor that programmers use.
You should see: a download starts.

2

Install it and open it.
You should see: a mostly-empty dark window with icons down the left side.

3

Click the Extensions icon in the left bar — four small squares, one detached.
Fourth or fifth icon down. Or press Ctrl+Shift+X ( Cmd+Shift+X on Mac).
You should see: a search box appear at the top left.

4

Type PlatformIO IDE into that search box.
You should see: "PlatformIO IDE" as the top result, with an alien-head logo.

5

Click Install on it. Then wait.
This one takes 5–10 minutes and downloads a lot. Leave it alone.
You should see: eventually, an alien-head icon appears in the left bar.
What is it? The thing that turns code into something the board understands, and sends it over USB.

6

Restart VS Code when it asks.
You should see: a small toolbar appear along the very bottom edge — a tick, an arrow, a plug.

7 Get the project folder onto your laptop.
If it's already there, skip to step 9. If not, download it from GitHub as a ZIP and unzip it somewhere you'll find again — Desktop is fine.

You should see: a folder containing firmware , server , and hardware .

8 Note where that folder is. You'll need the path twice.

You should see: a path you could type out.

9

In VS Code: File → Open Folder. Choose the firmware folder.
The firmware folder itself — not the folder above it. PlatformIO looks for platformio.ini in whatever you open, and that file lives in firmware .
You should see: platformio.ini and a src folder in the left panel.
Opened the wrong one? File → Open Folder again. No harm done.

10 Wait for the bottom bar to stop saying it's configuring.
First open downloads the ESP32 toolchain. Several minutes. Once only.
You should see: the bottom toolbar settles, with a tick ✓ and a right-arrow → on the left.

Steps 1–10. About 20 minutes, mostly waiting.

Part 1 — Install | Steps 1–10

## PART 2 — Plug in and flash the self-test

11

Plug the USB-C cable into the board, and the other end into your laptop.
You should see: a tiny LED on the board light up.
No light? Try a different cable. Many USB cables only carry power, not data — those will never work here even though the light might come on.

12

Click the alien-head icon in the left bar, then "Devices".
Under PIO Home. It lists everything plugged into your USB ports.
You should see: an entry like /dev/cu.usbmodem... (Mac) or COM5 (Windows). Nothing listed? Unplug, replug, refresh. Still nothing → it's the cable, 95% of the time.

13

In the left file panel, open the src folder.
You should see: main.cpp , selftest.cpp , pins.h , secrets.h.example and others.

14

Right-click secrets.h.example → Copy. Right-click empty space → Paste. Rename the copy to exactly secrets.h .
Right-click the new file → Rename. Delete the .example from the end.
You should see: both secrets.h.example and secrets.h in src .
Why: the code refuses to build without secrets.h . It's separate so your WiFi password never gets uploaded to GitHub.

15

Click secrets.h to open it. Fill in your WiFi name and password.
Keep the quote marks. Leave SERVER_HOST alone for now — step 33.
You should see: your real network name between the quotes. Save with Ctrl+S / Cmd+S . Important: the board only works on 2.4GHz WiFi. If your network is 5GHz-only it will never connect. Most home routers broadcast both.

16

At the very bottom of the VS Code window, click where it says Default or shows an environment name.
Bottom status bar, near the alien head. This is where you choose WHICH program to send. You should see: a menu listing seeed_xiao_esp32s3 and selftest .

Steps 11–21.

Part 2 — Plug in · Steps 11–16

## PART 2 continued — send the test to the board

17

Choose selftest .
This is the diagnostic program, not the real firmware. It checks every part and reports back. You should see: env:selftest in the bottom bar.

18

Click the right-arrow → in the bottom toolbar. That's Upload.
It builds the code and sends it to the board in one go. First time takes a few minutes. You should see: a wall of text, ending in green SUCCESS .
Red errors? Copy the last 20 lines and send them to me. Don't start editing code.

19

Upload failed saying it can't find the port? Hold BOOT, tap RESET, release BOOT, click Upload again.
Two tiny buttons on the board. This forces it into receive mode.
You should see: the upload proceed.

20

Click the plug icon 🔌 in the bottom toolbar. That's the Serial Monitor.
It shows messages the board sends back to your laptop.
You should see: a new panel open at the bottom.

21

Press the RESET button on the board and read the results.
The test runs immediately on boot, so you may need to reset to catch it from the start.
You should see: a list of [PASS] and [FAIL] lines, then a summary. It will ask you to press your button and will play a tone.
Fix the FIRST failure first — the ones below it are often just knock-on effects.

Steps 17–21.

Part 2 — Flash and test | Steps 11–21

## PART 3 — Start the AI server

22 Open a Terminal.
Mac: press Cmd+Space , type Terminal , press Enter.
Windows: press the Start key, type PowerShell , press Enter.
You should see: a window with a blinking cursor waiting for typing.

23

Check Python is installed. Type this and press Enter:

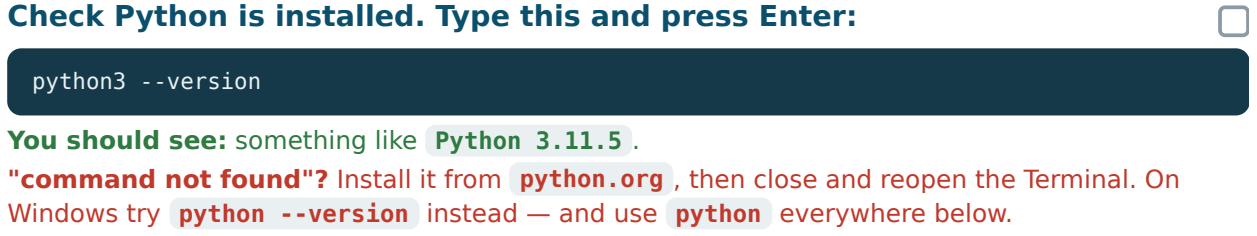
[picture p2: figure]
python3 --version

You should see: something like Python 3.11.5 .
"command not found"? Install it from python.org , then close and reopen the Terminal. On Windows try python --version instead — and use python everywhere below.

### 24 Move the Terminal into the server folder. Type cd (with a space), then

DRAG the server folder from your file browser onto the Terminal window, then press Enter.
cd means "change directory". Dragging pastes the path so you don't have to type it.
You should see: the prompt now mentions server .

25

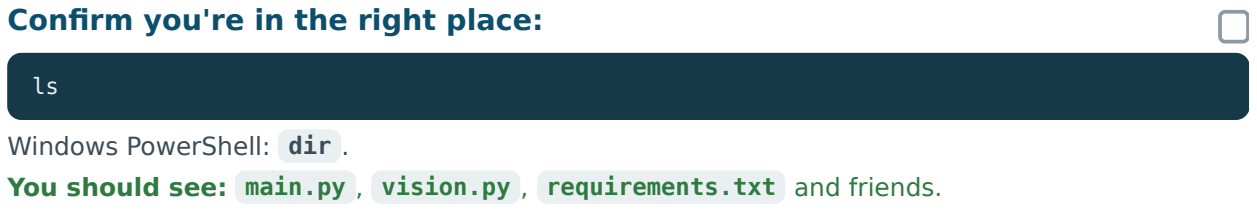
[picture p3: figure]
Confirm you're in the right place:; Windows PowerShell: dir .

You should see: main.py , vision.py , requirements.txt and friends. Don't see those? You're in the wrong folder. Redo step 24.

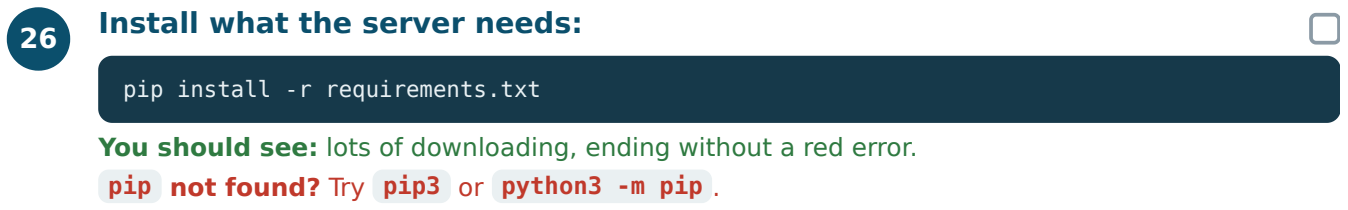
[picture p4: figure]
Install what the server needs:; pip install -r requirements.txt

You should see: lots of downloading, ending without a red error. pip not found? Try pip3 or python3 -m pip .

Steps 22–31. This runs on your laptop, not the board.

Part 3 — The server · Steps 22–26

## PART 3 continued — API keys and go

27

In VS Code, make a new file in the server folder called exactly .env
Yes, it starts with a dot and has no name before it. That's correct.
You should see: an empty .env file open.

28

Put your API keys in it, one per line, and save.

You should see: two lines with your real keys. No quote marks, no spaces around the = . This file is gitignored, so your keys never leave your laptop.

uvicorn main:app --host 0.0.0.0 --port 8000

You should see: Uvicorn running on http://0.0.0.0:8000
Leave this window open and running. Closing it stops the server. Open a SECOND Terminal for anything else.

### 30 Open a browser and go to http://localhost:8000/health

You should see: a short line of text or JSON — not an error page.

31

Test the AI with no hardware at all. Photograph a medicine box with your

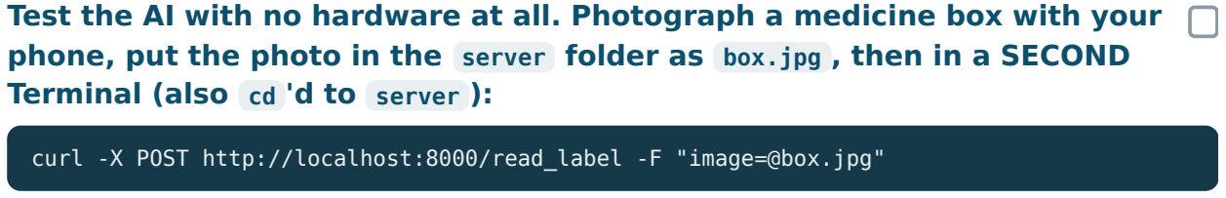
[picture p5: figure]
Terminal (also cd 'd to server ):

phone, put the photo in the server folder as box.jpg , then in a SECOND

curl -X POST http://localhost:8000/read_label -F "image=@box.jpg"

You should see: the AI describe what's on the box.
This is the most important test in the project. It proves the whole AI half works with zero wiring involved.

Steps 27–31.

Part 3 — The server | Steps 22–31

## PART 4 — Connect the two halves

32

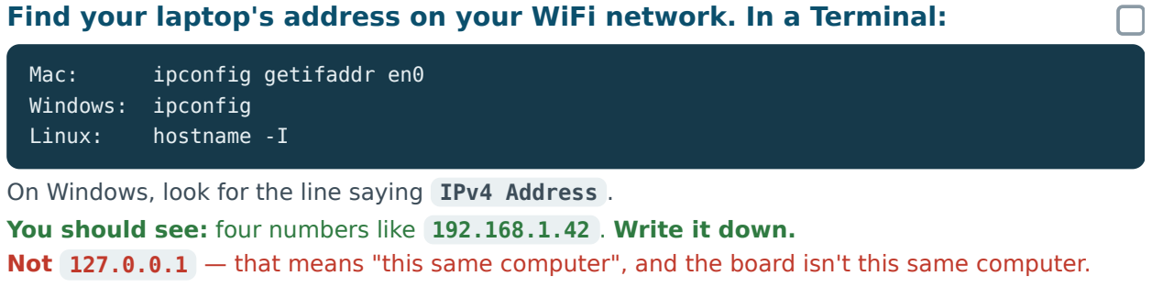
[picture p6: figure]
Mac:; ipconfig getifaddr en0; Windows: ipconfig; Linux:; hostname -I

Find your laptop's address on your WiFi network. In a Terminal:

On Windows, look for the line saying IPv4 Address .
You should see: four numbers like 192.168.1.42 . Write it down.
Not 127.0.0.1 — that means "this same computer", and the board isn't this same computer.

33

In VS Code, open src/secrets.h and put that address in as SERVER_HOST . Save.
You should see: #define SERVER_HOST "192.168.1.42" with your number.

### 34 With selftest still selected, click Upload again, then open the Serial

Monitor.
You should see: the test run again — and this time [PASS] Server reachable .
Still failing? The laptop and the board must be on the same WiFi network. Not one on guest WiFi and the other on the main one.

### 35 Only when every self-test line passes: switch the environment back to

seeed_xiao_esp32s3 .
Same bottom-bar menu as step 16.
You should see: env:seeed_xiao_esp32s3 in the bottom bar.
Don't skip ahead to this. The real firmware assumes the hardware works — debugging it is far harder than debugging the self-test.

Steps 32–38. The finish line.

Part 4 — Connect · Steps 32–35

## PART 4 continued — the finish line

36

Click Upload. Then open the Serial Monitor.
You should see: WiFi connected , then Glasses ready .

37

Point the camera at a medicine box and press your button.
You should see: the Serial Monitor say it triggered, the server Terminal log a request, and the speaker read the label out loud.
That's the whole product working.

38 Do it ten more times with different objects.
A tin, something handwritten, something in bad light, something with a barcode.
You should see: ten out of ten trigger and speak. Anything less is what you fix next.

Keep these three windows open whenever you're working: VS Code with the Serial Monitor, the Terminal running the server, and a second Terminal for everything else. Almost every problem shows up in one of the first two.

Steps 36–38.

Part 4 — Connect | Steps 32–38

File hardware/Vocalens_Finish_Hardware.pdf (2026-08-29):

# Finish the Hardware

### 44 steps, from soldered headers to a working device on your face

Good news: the headers change everything for the better. Every board connection is now push-on. Only ONE joint still needs the iron — the touch disc, step 19. Everything else plugs together and can be unplugged again when you're debugging.

One thing to know before you print pods. Headers plus a pushed-on jumper socket add about 10mm to the board's height. The pod's vertical size follows that — a bare board gives a 10mm pod; with headers it's 19mm. That's the bulk the two-pod split existed to avoid. You don't have to decide yet: step 39 lays out the choice, and both files are ready.

THE SIX PARTS

Steps | Part | Iron needed?
1–8 | Check the headers you just soldered | Only if you find a bridge
9–17 | Plug in the amp and speaker | No
18–21 | Make the touch pad | Yes — one joint
22–28 | First power-on and flash the firmware | No
29–37 | Start the server, test the camera | No
38–44 | Test audio, then into the pods | No

Same rules as before. Do one step. Check the green line actually happened. Only then move on. If the green line didn't happen, the red line tells you what to do.

V O C A L E N S · H E A D E R S F I T T E D

Finish the Hardware | Cover

## PART 1 — Check what you just soldered

1 Make sure the USB cable is unplugged.
You should see: nothing connected to the board.

2

Lower your eye to table level and look along the row of 7 pins.
From the side, like looking along a fence — not down from above.
You should see: 7 separate solder cones with clear gaps between them.
If two are joined: wipe the iron tip clean, drag it firmly across the join and off the edge of the board. Look again.

3 Do the same on the other row of 7.
You should see: 7 more separate cones.

4

Set the multimeter to beep/continuity and touch the probes together.
The dial position marked ")))" or a diode triangle.
You should see: it beeps when they touch, silence when apart.

5

Touch one probe to the 3V3 pin, the other to the GND pin.
Touch the metal pins themselves, not the plastic.
You should see: SILENCE.
If it beeps: STOP. Those two are joined by stray solder — a dead short that can kill the board the moment you plug in. Find it and drag it off. Do not continue until this is silent.

6

Test every neighbouring pair on both rows.
5V – GND , GND – 3V3 , 3V3 – D10 , D10 – D9 , D9 – D8 , D8 – D7 , then the same down the D0 – D6 row.
You should see: silence every time. That's 12 tests.
Any beep = a bridge. Same fix. Worth the two minutes — this is the single most common way a soldered board gets destroyed.

7

Check the Sense expansion board is still firmly attached underneath.
The smaller board with the camera socket on it. Press it gently — it should be flush with no gap at either end.
You should see: the two boards sitting tight together.
If it's loose: press it back on. Heat from soldering can loosen it.

8

Check the camera ribbon is still latched in its connector.
The dark flip-latch should be pressed flat. Tug the ribbon very gently — it must not move.
You should see: a seated ribbon, latch closed.
If it moved: lift the latch, push the ribbon fully in with the contacts facing down, press the latch flat.

Steps 1–8. Before anything gets powered.

Part 1 — Check the headers | Steps 1–8

## PART 2 — Plug in the amp and speaker

9

Find five jumper wires with a plastic SOCKET on both ends.
"Female-to-female" — a small plastic block with a hole at each end. Your kit has 20. You want red, black, yellow, green, blue if possible.
You should see: five wires, socket at both ends.
Only male-to-male (bare pins)? Those won't work on header pins. Use female-to-female, or female-to-male with the socket end on the board.

10

Look at your amplifier board and find its pin labels.

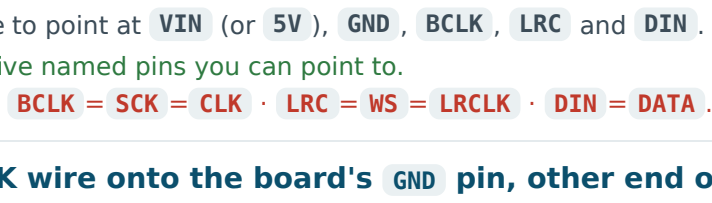
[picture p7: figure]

You want to be able to point at VIN (or 5V ), GND , BCLK , LRC and DIN .
You should see: five named pins you can point to.
Different names? BCLK = SCK = CLK · LRC = WS = LRCLK · DIN = DATA . Same things.

11

Push the BLACK wire onto the board's GND pin, other end onto the amp's
GND .
Push straight down until it's fully seated. It should need a small amount of force.
You should see: the socket fully covering the pin, no metal showing.

12

RED wire: board 3V3 → amp VIN .
You should see: two wires connected.
Amp says 5V only? Use the board's 5V pin instead — but note it only carries power while USB is plugged in.

13

YELLOW wire: board D8 → amp BCLK .
You should see: three wires connected.
Note: D8 is the pad label printed on the board. It is not GPIO 8. Go by the printed label.

14 GREEN wire: board D9 → amp LRC .
You should see: four wires connected.

15

BLUE wire: board D10 → amp DIN .
You should see: five wires connected. The whole audio link is done.

16

Connect the speaker's two wires to the amp's two output pins.
Labelled OUT+ / OUT− or just + / − . Screw terminals: strip 5mm, insert, tighten. Pins: push jumpers on. Bare pads: this is the one place you may need the iron.
You should see: the speaker attached to the amp.
Which wire to which? Doesn't matter. A single speaker has no correct way round.

17

Leave GAIN , SD and SHUTDOWN completely unconnected.
If your amp has these extra pins, ignore them.
You should see: nothing plugged into them.
Why it matters: SD usually means shutdown. Connecting it to ground silences the amp completely, and you will spend an hour hunting a fault that isn't there.

Steps 9–17. No soldering.

Part 2 — Amp and speaker | Steps 9–17

## PART 3 — The touch pad · PART 4 — Power and flash

18

Rub sandpaper over one face of a coin until it looks dull and scratched.
Any coin, or a wide screw head. Scuff an area about the size of a pea.
You should see: a dull scratched patch, not shiny.
Why: solder will not stick to a shiny coin. This step is the whole reason the touch pad works.

19

Solder one end of a jumper wire to the scuffed patch. The only joint left.
Use a female-to-male jumper and solder the male (pin) end to the coin, so the socket end is free to push onto the board. A coin is a big lump of metal — hold the iron on it 5–10 seconds, not 2. You should see: the wire firmly attached to the coin.
If solder won't stick: not scuffed enough, or not hot enough. Scuff harder, hold longer.

20

Push the coin wire's free end onto the board pin labelled D2 .
Left-hand row, third pin down from the USB end.
You should see: the coin connected to D2 and nothing else.

21

Re-test 3V3 to GND with the meter, one last time.
Everything is now connected, so this catches anything the wiring introduced.
You should see: silence.
If it beeps now but didn't at step 5: the amp or a jumper is the cause. Unplug the amp and test again.

22

Plug in the USB cable.
You should see: a small LED on the board light up.
Nothing? Many USB cables are charge-only with no data wires. Try a different cable before assuming the board is faulty.

23 Within 5 seconds, dab a fingertip on the board and on the amp.
You should see: both cool or barely warm.
If anything is hot: UNPLUG NOW. You have a short. Go back to step 5.

24 Open the firmware folder in VS Code with the PlatformIO extension.
You should see: PlatformIO recognises the project and shows a build toolbar at the bottom.

25

Copy src/secrets.h.example to a new file called src/secrets.h .
You should see: both files in the src folder.

26

Put your WiFi name and password into secrets.h . Leave the IP for now.
You should see: WIFI_SSID and WIFI_PASSWORD filled in.
Note: the ESP32 only works on 2.4GHz WiFi. If your network is 5GHz-only it will never connect.

27

Press Build (the tick icon).
You should see: SUCCESS in the terminal. First build downloads a lot and takes several minutes. Errors? Send me the last 20 lines. Don't start changing code.

You should see: a progress bar, then SUCCESS .

Steps 18–28. One solder joint, then software.

Parts 3–4 — Touch pad, power, flash | Steps 18–28

Port not found? Hold the BOOT button, tap RESET, release BOOT, upload again.

## PART 5 — Server and camera

Camera first, audio second — never both at once. If both are on and it fails, you can't tell which half broke.

29 Open a terminal in the server folder and install what it needs.

You should see: packages install, ending without an error.
pyzbar fails? Needs the system zbar library — Mac: brew install zbar .

30

Create a file called .env in the server folder with your API keys.
You should see: a .env file. It's gitignored, so it won't be committed.

31

uvicorn main:app --host 0.0.0.0 --port 8000

You should see: Uvicorn running on http://0.0.0.0:8000 . Leave this terminal open.

32

In a browser, open http://localhost:8000/health .
You should see: a small JSON response, not an error page.

33

Test the AI with no hardware at all — photograph a medicine box with your phone, copy it to your laptop, and run:

You should see: the server describe what's on the box.
The most valuable test in the project — it proves the AI half works with no wiring involved. Try ten real products.

Steps 29–37. Camera only. No audio yet.

Part 5 — Server and camera | Steps 29–33

## PART 5 continued — point the board at your laptop

34

Find your laptop's IP address on the local network.
Mac ipconfig getifaddr en0 · Windows ipconfig (IPv4) · Linux hostname -I You should see: something like 192.168.x.x . Write it down.

35

Put that IP into secrets.h as SERVER_HOST , then Upload again.
You should see: another SUCCESS .
Laptop and board must be on the SAME WiFi network. Not guest network, not phone hotspot on one and home WiFi on the other.

36 Open the Serial Monitor (the plug icon) and press RESET on the board.
You should see: Connecting to WiFi then WiFi connected .
Says FAILED? Check the password, and check it's a 2.4GHz network.

37

Touch the coin. Watch BOTH the serial monitor and the server terminal.
You should see: the board report a capture, and the server log a request arriving.
Camera fails? PSRAM, not wiring — fixed in platformio.ini , so rebuild after pulling. Nothing on touch? Try holding the coin rather than tapping.

Steps 34–37.

Part 5 — Server and camera | Steps 34–37

## PART 6 — Audio, then onto your face

38

Touch the coin again and listen to the speaker.
You should see (hear): a voice reading out whatever the camera is pointed at. That's the whole product working.
Silence? Check SD / SHUTDOWN is unconnected (step 17). Then meter amp VIN → GND , expect ~3.3V.
Static or buzzing? Yellow and green are swapped. D8 →BCLK, D9 →LRC.
Very quiet? Try the board's 5V pin instead of 3V3 , if your amp is rated for it.

39 Decide which pod plate to print.
Keeping the headers → print FINAL_petg_plate_HEADERS.stl . Pods are 19mm tall. Stick out more, but nothing to undo.
Removing the headers → print FINAL_petg_plate.stl . Pods are 10mm tall and sit much closer to the head, but you'd desolder the headers and solder wires flat to the pads.
You should see: one file chosen.
My honest suggestion: print the HEADERS version now. A working chunky prototype beats an elegant one that isn't finished. Slimming it down is a week-4 job if you have time.

40

Print your chosen plate in PETG, and FINAL_tpu_rings.stl in TPU.
Layer height 0.16mm, 4 perimeters. The rings are tiny — about 10 minutes each.
You should see: two pod bases, two lids, and four rings.

41

Slide two rings onto one temple arm of your glasses, from the ear end.
They're deliberately undersized — they should need a firm stretch to go on.
You should see: rings that grip and don't slide when pushed.
Too loose? Reprint with a SMALLER opening — not larger. Reduce RING_IN_OUT by 0.5mm in the .scad .
Won't stretch on? Reduce RING_WALL to 1.0mm — a thinner wall stretches far more easily.

42

Put the board and camera into the front pod, amp and speaker into the rear pod. No glue yet.
Camera lens lined up with the hole. Speaker under the grille holes.
You should see: both lids close flat.
A lid won't close? Something is taller than the CAD expects. Measure it and tell me the number rather than forcing the lid.

43

Slide each pod onto its rings, along the arm.
The slot slides onto the rail from the end — it won't push on from above. That's the point. You should see: pods that sit firmly and can't be pulled straight off.

44

Put the glasses on and wear them for ten minutes.
You should see: nothing pressing into your head, arm not splayed, pods not sliding. Something digs in? Tell me where. That's a CAD fix and it's a quick one.

That's the hardware done. Everything after this is reliability, the wake word, and making it look finished.

Steps 38–44.

Part 6 — Audio and assembly | Steps 38–44

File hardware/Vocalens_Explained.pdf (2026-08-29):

# What Am I Building?

The whole thing, from zero, no assumed knowledge

IN ONE SENTENCE

### You clip two small plastic boxes onto the arm of a pair of glasses you already own. One box has a camera. The other has a speaker. You tap it, it photographs

whatever you're looking at, and it reads the writing out loud to you.

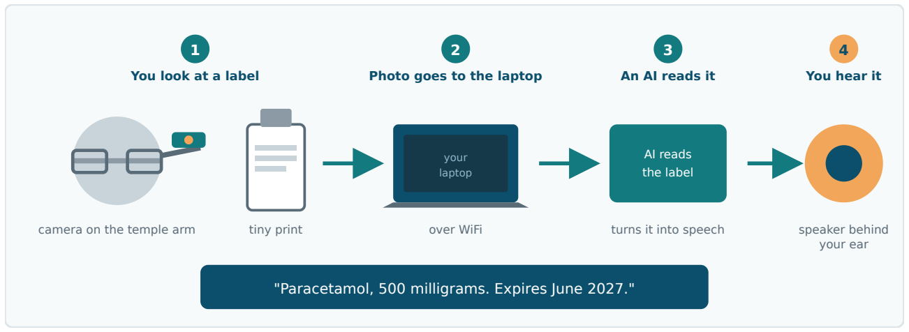
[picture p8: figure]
You look at a label; Photo goes to the laptop; An AI reads it; You hear it; camera on the temple arm; tiny print; your laptop; over WiFi; AI reads the label; turns it into speech; speaker behind; your ear

"Paracetamol, 500 milligrams. Expires June 2027."

The entire product. Four steps, about five seconds.

The board on your desk is not clever. It only takes a photo, sends it, and plays the sound that comes back. All the thinking happens on your laptop. That's deliberate — it means you can fix and improve the smart part without ever re-flashing the hardware.

WHY GLASSES AND NOT A HANDHELD GADGET
Because people put handheld things down and lose them. Glasses are already on your face — you can't misplace the thing you're wearing. That's the entire product thesis in one line, and it's what you say on stage.

THE THREE THINGS THAT MAKE IT MORE THAN A CAMERA

Feature | What it does for the person wearing it
It reads barcodes first | If there's a barcode, it looks the product up in a database instead of asking the AI. Faster, free, and more accurate on packaged goods.

It remembers a little
about you

Either your dosage-relevant facts, or things you asked it to remember. Which one depends on a single setting.

It admits when it
can't see

On a bad photo it says "I can't see that clearly" rather than guessing. For someone who can't check the answer, that matters more than being usually right.

V O C A L E N S · P L A I N E N G L I S H

Plain English guide | Page 1

1

## The parts, and what each one does

Every physical thing in the build

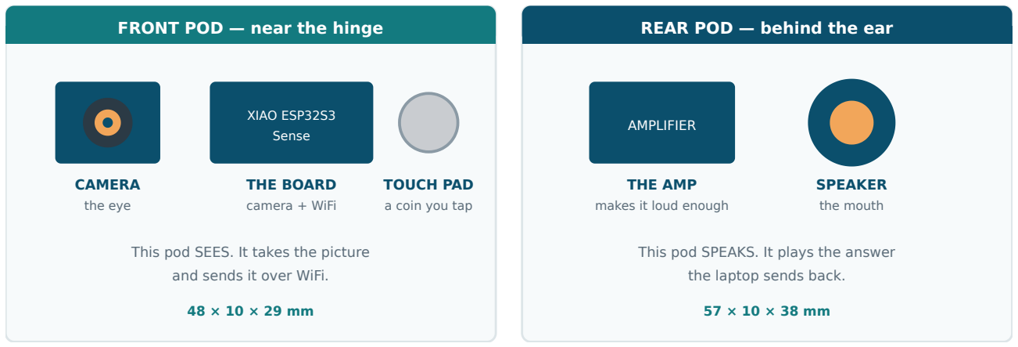
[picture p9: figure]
FRONT POD — near the hinge; CAMERA the eye; XIAO ESP32S3 Sense; THE BOARD camera + WiFi; TOUCH PAD a coin you tap; This pod SEES. It takes the picture and sends it over WiFi.; REAR POD — behind the ear; AMPLIFIER; THE AMP makes it loud enough; SPEAKER the mouth; This pod SPEAKS. It plays the answer the laptop sends back.

Two boxes. One sees, one speaks. Five wires join them along the arm.

WHY TWO BOXES INSTEAD OF ONE
If you put all five components in one box it becomes a big lump sitting on the side of your head. Splitting them means each box is small and thin. The camera has to be at the front (that's where you look) and the speaker wants to be near your ear. So the split matches where things naturally belong.
Wire colour | What it carries | In plain words
Red | 3.3 volts of power | Feeds the amp
Black | Ground | The return path — every circuit needs one
Yellow | Bit clock | Three wires that together carry digital sound from the board to the amp
Green | Word select
Blue | Data
White | Touch signal | Stays inside the front pod — tells the board you tapped it

Don't worry about what "bit clock" means. Those three wires are a standard called I2S. You never have to understand it — you just have to connect yellow-to-yellow, green-to-green, blue-to-blue. The code handles the rest.

The parts | Page 2

2

## The problem your sketch solves

Why the mount is being redesigned

WHAT WE HAD BEFORE
The box and the clip were the same part. The TPU box had a C-shaped channel moulded into its underside, sized to grip one exact thickness of temple arm. Change glasses, and the box no longer fits — you reprint the whole box.

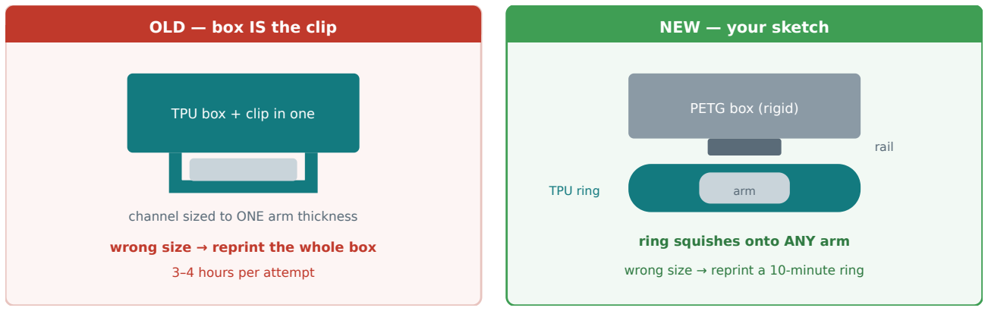
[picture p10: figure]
OLD — box IS the clip; TPU box + clip in one; channel sized to ONE arm thickness; wrong size → reprint the whole box; 3–4 hours per attempt; NEW — your sketch; PETG box (rigid); rail; TPU ring; arm; ring squishes onto ANY arm; wrong size → reprint a 10-minute ring

The change: stop asking one part to do two jobs.

This is the real win, and it's worth saying out loud in the pitch. The box never touches the glasses. The ring does all the gripping. So the expensive part — the one with electronics glued into it — never has to change when the glasses change. You print rings, not pods.

WHY THE TWO DIFFERENT PLASTICS

Material | Feels like | Used for, and why
TPU | A rubber shoe sole — bends, springs back | The ring. It has to stretch over the arm and squeeze. Rigid plastic would snap or stay loose; TPU grips a range of sizes and survives being pulled on and off hundreds of times.
PETG | A fizzy-drink bottle — firm, slightly tough

The box. It must hold its shape so components don't rattle and the lid stays shut. It never flexes, so it never fatigues.

PLA | Hard and a bit brittle

Test prints only. Fastest and cheapest to print — use it while you're iterating, not in the final build.

Soft and rigid is the whole trick. Every clip-on product works this way — the springy part grips, the stiff part holds the electronics. If you only take one idea from this page, take that one.

WHAT THE RING BUYS YOU, IN PRACTICE

Situation | Old design | Ring design
A judge wants to try it on their own glasses | Won't fit | Slide on a spare ring
The clip is slightly too loose | Reprint the pod (3–4 hrs) | Reprint a ring (10 min)
A teammate wants to test- wear it | Only if same glasses | Their own ring, same pod
The mount cracks the night before | Electronics stuck in a broken pod | Swap the ring, pod untouched
The mounting problem | Page 3

That last row is the one that should sell you on it. With the old design the thing that flexes most is also the thing your electronics are glued into. The ring design moves all the flexing into a part that costs

An interlock is just a shape that slides into a matching shape and then can't be pulled straight out. Think of a Lego brick, or a drawer runner. Ours is a wedge — wide at the top, narrow at

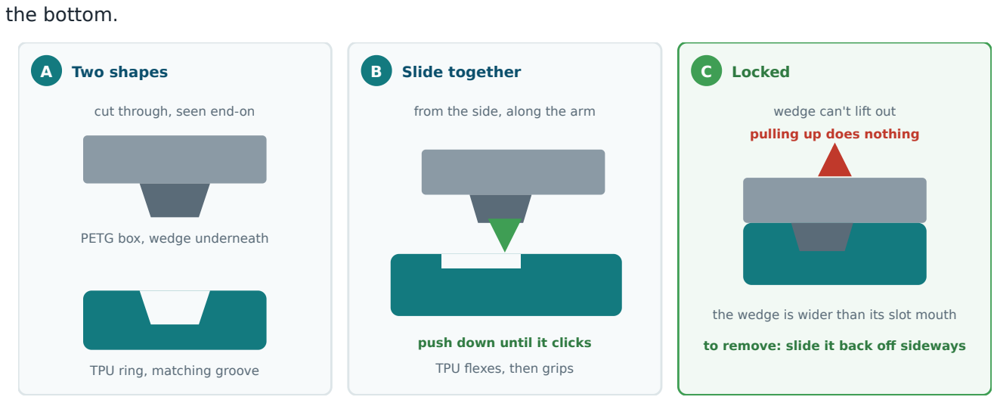
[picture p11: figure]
the bottom.; A Two shapes; cut through, seen end-on; PETG box, wedge underneath; TPU ring, matching groove; B Slide together; from the side, along the arm; push down until it clicks; TPU flexes, then grips; C Locked; wedge can't lift out pulling up does nothing; the wedge is wider than its slot mouth; to remove: slide it back off sideways

A wedge in a matching groove. Slides on sideways, won't pull off upwards.

Why a wedge and not a straight peg? A straight peg only holds by friction, and friction on a printed part fades as it wears. A wedge holds mechanically — the shape itself blocks the exit. It stays tight even when it's worn smooth.

WHY THIS DIRECTION MATTERS
The slide-on direction runs along the temple arm, front to back. That's deliberate: gravity and knocks push the pod down and outward, and the interlock resists exactly those. The only direction that releases it is the one nothing pushes it in by accident.

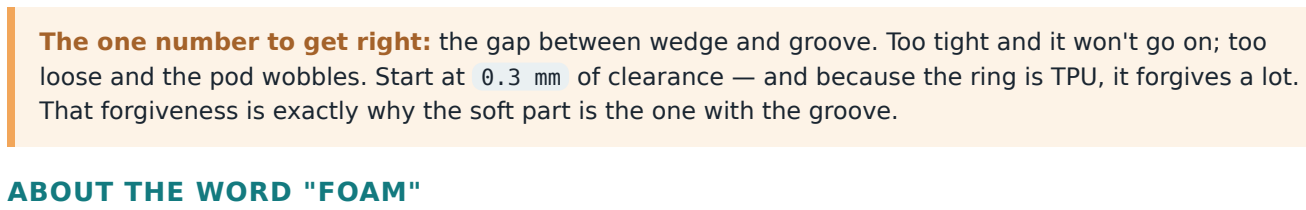
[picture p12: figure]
ABOUT THE WORD "FOAM"

The one number to get right: the gap between wedge and groove. Too tight and it won't go on; too loose and the pod wobbles. Start at 0.3 mm of clearance — and because the ring is TPU, it forgives a lot. That forgiveness is exactly why the soft part is the one with the groove.

Your sketch says foam ring. There are two ways to get that, and they're both fine — worth knowing the difference before you print:

Approach | What it means
Printed soft TPU (recommended) | Print the ring in TPU at low infill with a soft pattern. It comes off the printer already squishy. One part, nothing to glue, nothing to fall off.
TPU ring + stick-on foam | Print a thinner TPU ring and line the inside with a strip of adhesive foam tape. Grips even harder and is more forgiving of odd-shaped arms — but the tape is one more thing that can peel off mid-demo.

Start with printed TPU. Add foam tape only if the ring turns out to slip on the actual glasses. Fewer parts is fewer things that fail on stage.

The interlock | Page 4

## 4 Where things actually stand

Read this before you print anything else

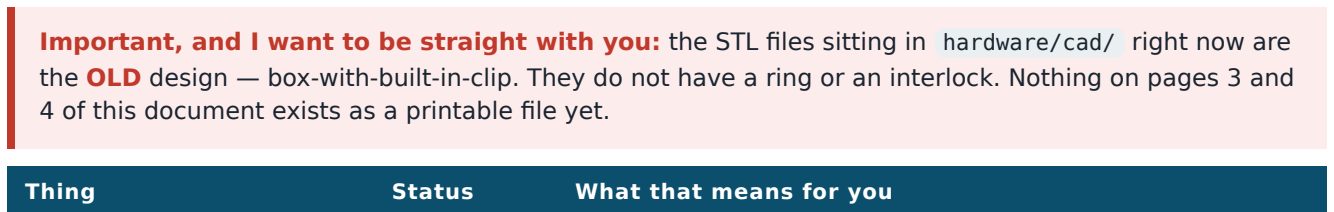
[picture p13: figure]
Thing; Status; What that means for you

Important, and I want to be straight with you: the STL files sitting in hardware/cad/ right now are the OLD design — box-with-built-in-clip. They do not have a ring or an interlock. Nothing on pages 3 and 4 of this document exists as a printable file yet.

Server + AI | Done | Works today, no hardware needed. Test it now.
Firmware skeleton | Done | Wake word still stubbed — that's planned, not broken.
Old pod STLs | Printable | Will work, but only on one arm size, and needs fit-test tuning.
Ring + interlock | Not built | Your sketch. Needs new CAD before it can be printed.

SO WHAT DO YOU DO ABOUT IT
You have two sane options. Neither is wrong — it depends on how much time you have before demo

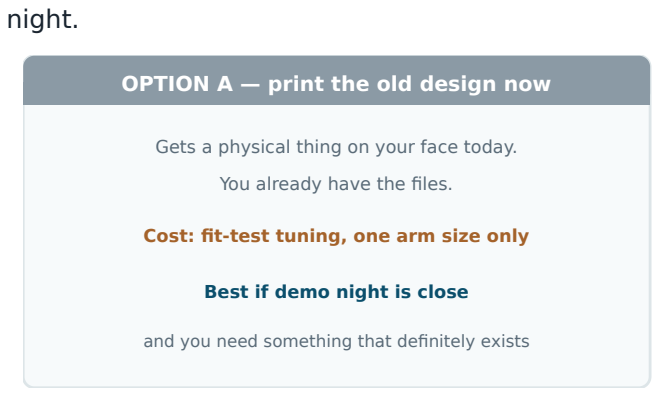
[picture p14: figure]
night.; OPTION A — print the old design now; You already have the files.; Best if demo night is close

Gets a physical thing on your face today.

Cost: fit-test tuning, one arm size only

and you need something that definitely exists

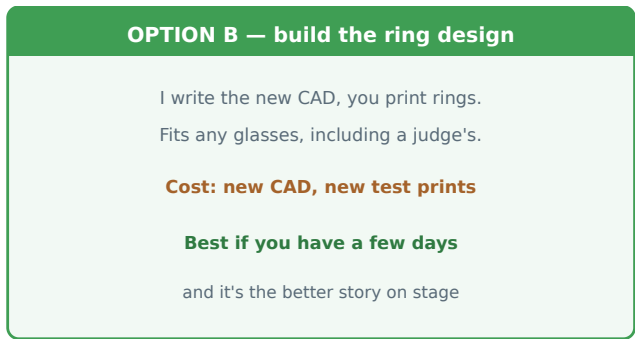
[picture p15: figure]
OPTION B — build the ring design; I write the new CAD, you print rings.; Fits any glasses, including a judge's.; Cost: new CAD, new test prints; Best if you have a few days; and it's the better story on stage

You can also do both — print the old pods to keep testing while the new CAD is written.

My honest recommendation: do both, in that order. Print the old design this week so you always have a working physical prototype to fall back on. Then build the ring version as the upgrade. A hackathon is won by the team that has something that works, not the team with the best design that didn't get printed in time.

Nothing you've done is wasted either way. The electronics, the wiring, the server, the box dimensions — all identical between the two. The only thing that changes is how the box attaches to the glasses.

Where things stand | Page 5

?

## Every word explained

Nothing here is assumed knowledge

Word | What it actually means
Pod | One of the two small printed boxes. Front pod = camera. Rear pod = speaker.
Temple arm | The bit of the glasses that goes over your ear.
XIAO ESP32S3 Sense | The little computer board. Has WiFi and a camera socket. About the size of a stamp.
Firmware | The program that runs on the board (as opposed to on your laptop).
Flash | To copy the firmware onto the board over USB. "Flashing the board" = installing the program.
Server | The program running on your laptop that receives photos and answers them.
Endpoint | One specific thing the server can do, named like a web address. /read_label is an endpoint.
curl | A command that sends something to the server from your terminal. Lets you test with no hardware.
I2S | The three-wire standard for sending digital sound. Yellow, green, blue.
Amp / amplifier | Turns a weak digital sound signal into one strong enough to drive a speaker.
Capacitive touch | The board can sense a finger near a metal pad. No button needed — just a wire and a coin.
PSRAM | Extra memory the camera needs. Must be set to "OPI PSRAM" or the camera won't start.
Wake word | Saying "Hey Vocalens" to trigger it instead of tapping. Hardest part — saved for last.
STL | A 3D model file. What you hand to the printer software.
OpenSCAD / .scad | Where the 3D model is written as code. Change a number, re-export the STL.
Slicer | Software that turns an STL into printer instructions. You set layer height and material here.
TPU / PETG / PLA | Rubbery / firm / hard-and-brittle. See page 3.
Interlock | A shape that slides into a matching shape and then can't be pulled out.
Fit test | A tiny 3-minute print used only to check the clip grips before printing a whole pod.
Dry-fit | Putting parts together loosely, with no glue, just to check they fit.
Vision model / VLM | An AI that looks at a picture and describes it. The thing that actually reads the label.
Barcode fast path | If there's a barcode, look it up in a database instead of asking the AI. Faster and free.
Profile | The saved info about one user — either dosage facts, or reminders. Never both.
Guardrail | The rule stopping the AI giving medical advice. It reads labels; it never says what to take.

If you remember nothing else: the glasses hold two boxes, the boxes talk to your laptop, the laptop does the thinking, and the answer comes back as speech. Everything else on these six pages is detail underneath that one sentence.

Glossary | Page 6

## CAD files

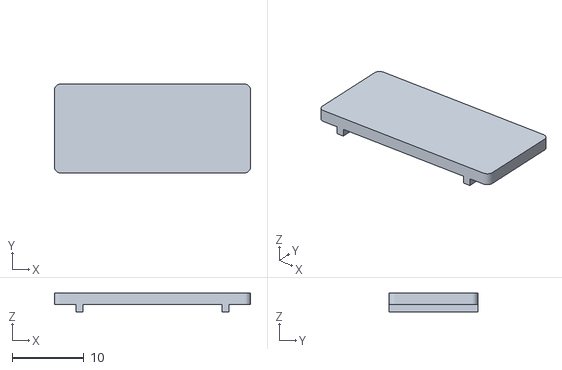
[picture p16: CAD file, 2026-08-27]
hardware/cad/bone_conduction/rear_lid.stl
27.4 x 12.4 x 2.60

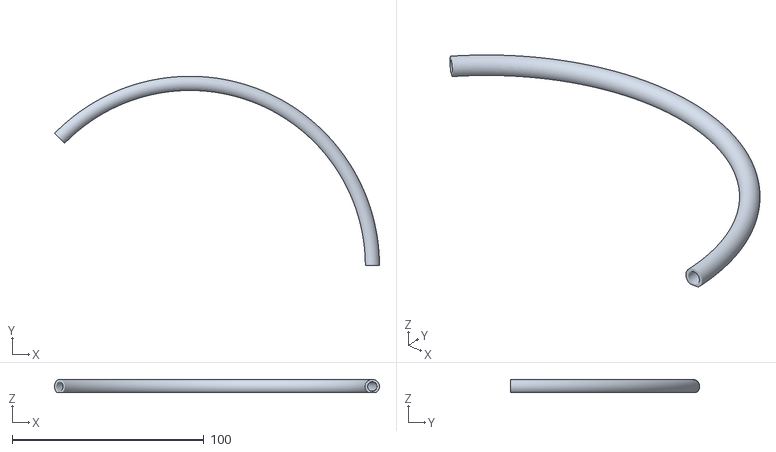
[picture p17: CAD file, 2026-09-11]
hardware/cad/final_cable_tube.stl
169.3 x 98.7 x 6.90

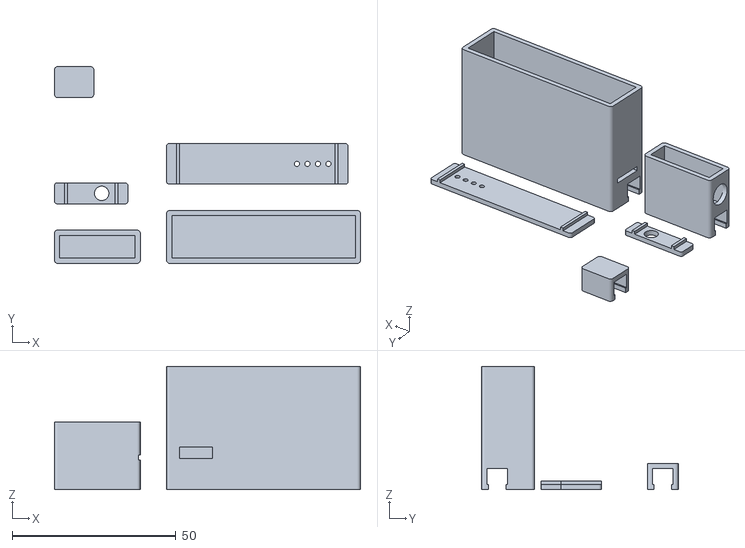
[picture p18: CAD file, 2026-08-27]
hardware/cad/bone_conduction/plate.stl
93.4 x 60.1 x 37.6

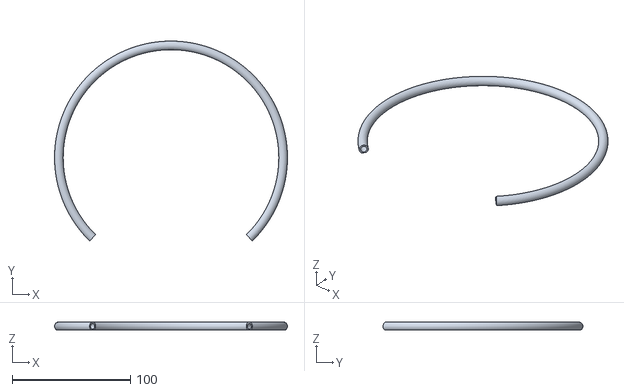
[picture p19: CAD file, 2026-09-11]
hardware/cad/FINAL_tpu_tubes_1PIECE.stl
197.4 x 169.3 x 6.90

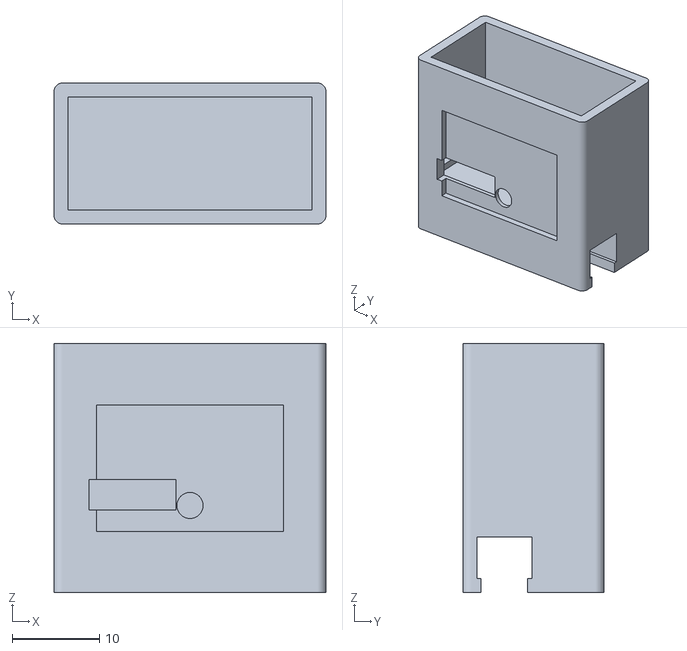
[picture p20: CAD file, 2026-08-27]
hardware/cad/bone_conduction/rear_base.stl
31.2 x 16.2 x 28.6

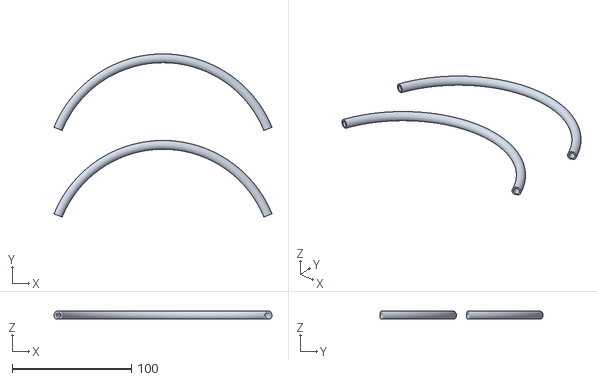
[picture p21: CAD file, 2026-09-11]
hardware/cad/FINAL_tpu_tubes.stl
182.8 x 136.9 x 6.90

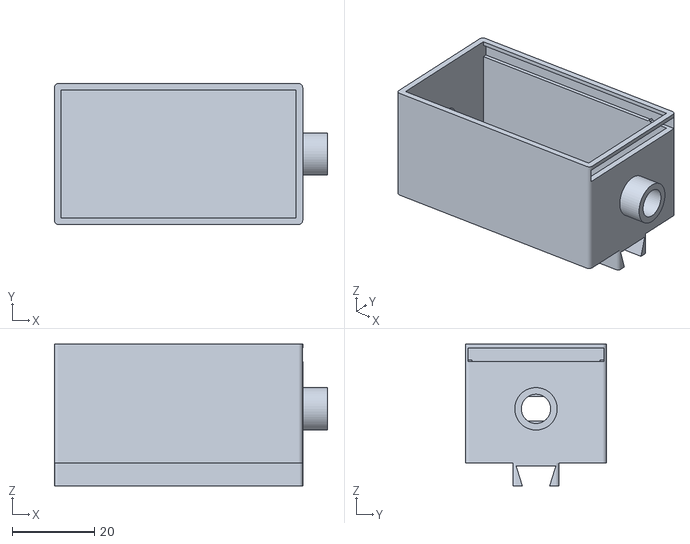
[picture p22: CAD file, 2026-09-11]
hardware/cad/final_rearaudio_base_HEADERS.stl
66.2 x 34.2 x 34.4

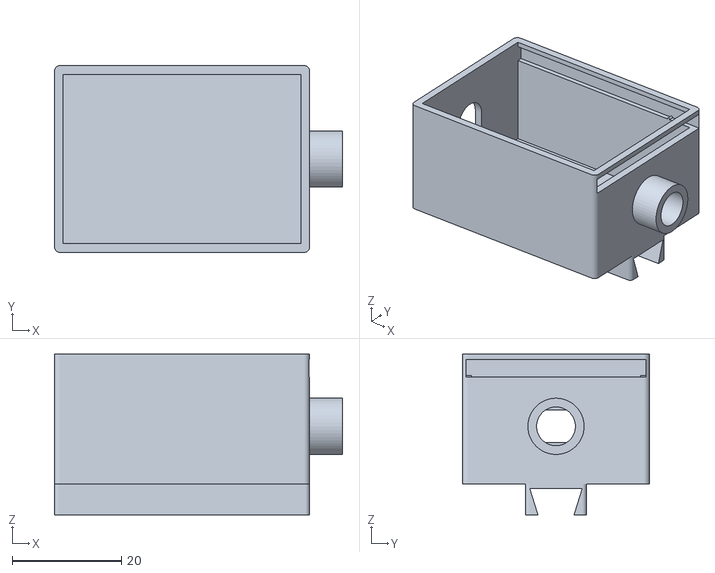
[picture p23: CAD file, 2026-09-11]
hardware/cad/final_frontboard_base_HEADERS.stl
52.7 x 34.2 x 29.4

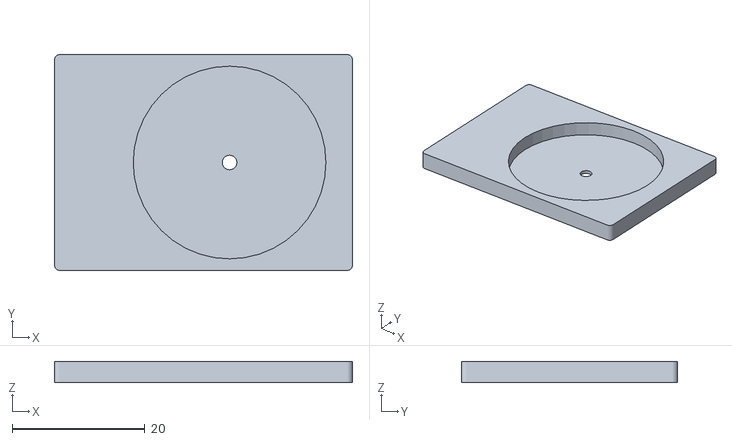
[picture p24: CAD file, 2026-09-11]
hardware/cad/final_frontboard_lid.stl
44.9 x 32.5 x 3.20

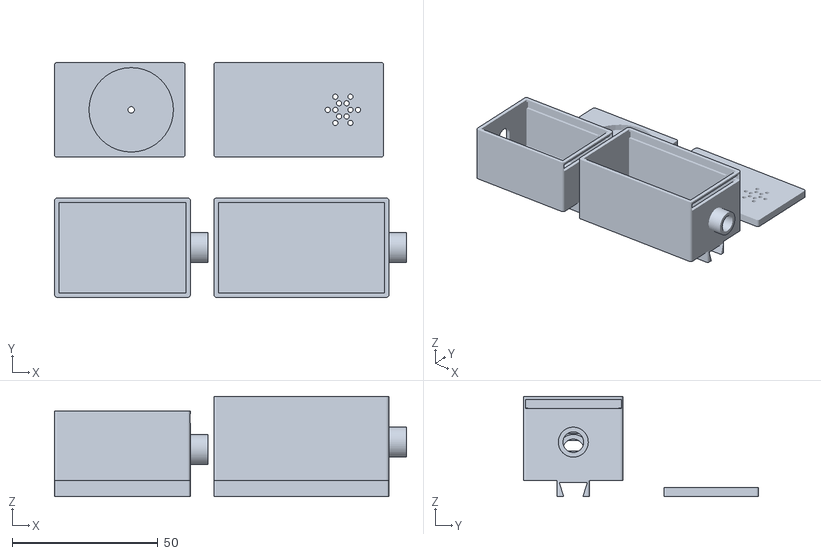
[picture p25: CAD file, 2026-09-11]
hardware/cad/FINAL_petg_plate_HEADERS.stl
120.9 x 80.7 x 34.4

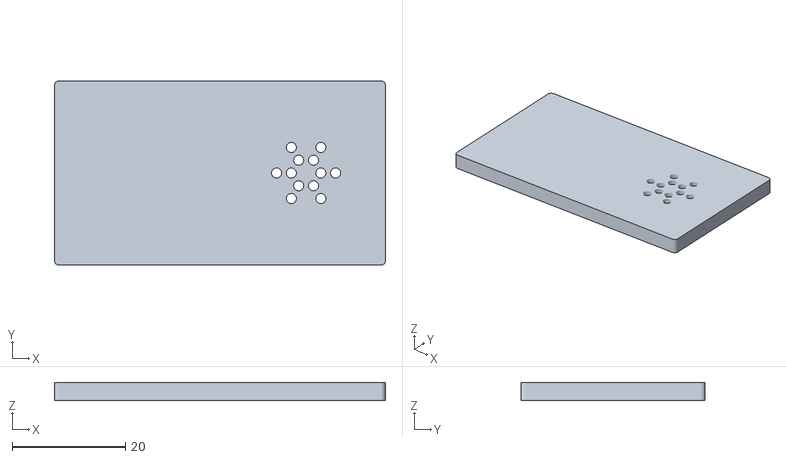
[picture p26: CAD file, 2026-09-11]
hardware/cad/final_rearaudio_lid_HEADERS.stl
58.4 x 32.5 x 3.20

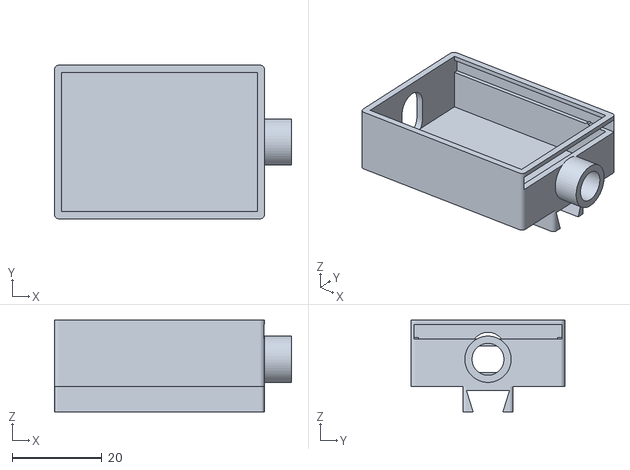
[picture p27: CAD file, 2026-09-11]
hardware/cad/final_frontboard_base.stl
52.7 x 34.2 x 20.4

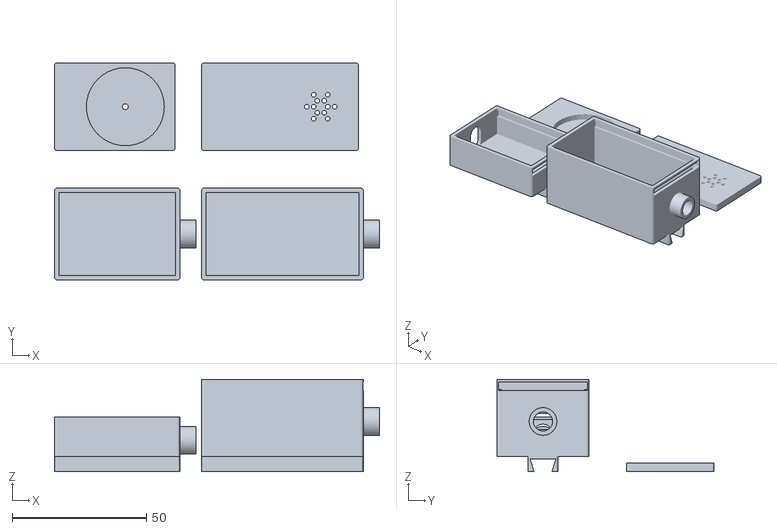
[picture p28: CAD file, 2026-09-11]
hardware/cad/FINAL_petg_plate.stl
120.9 x 80.7 x 34.4

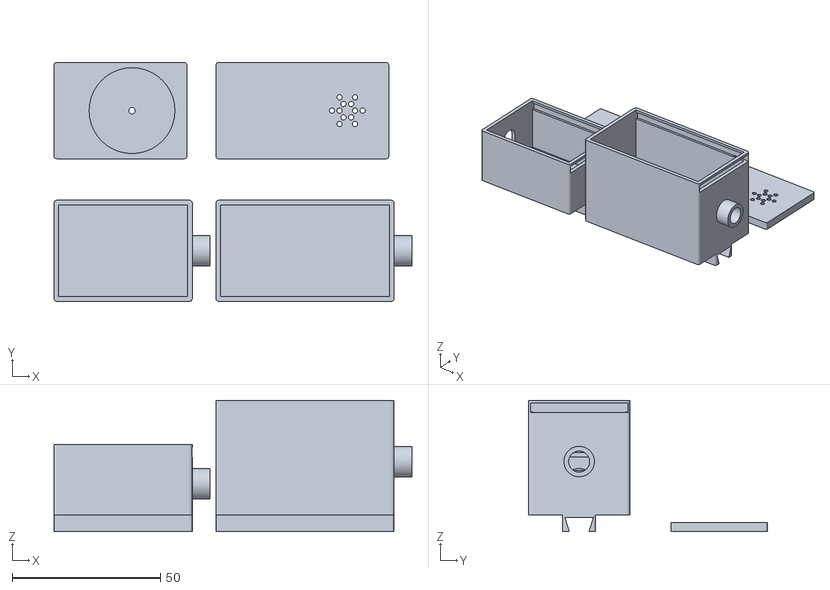
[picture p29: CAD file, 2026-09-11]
hardware/cad/FINAL_petg_plate_AMPSOCKETS.stl
120.9 x 80.7 x 44.4

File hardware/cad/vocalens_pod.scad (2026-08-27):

// Vocalens temple-clip pods — first mechanical prototype
//
// Design approach: rather than fabricate a full glasses frame (hinges, nose
// bridge, lens-fit) from scratch, these pods clip onto the temple arm of an
// existing pair of glasses. Two small pods instead of one big one, split by
// where the weight naturally belongs:
//   - FRONT POD: near the hinge. Houses ONLY the camera module, detached
//     from the XIAO and connected back by its FPC ribbon, plus the touch
//     pad. The camera has to be at the front (it must aim forward) but
//     nothing else does — so nothing else goes here. This is what keeps
//     the visible, forward part of the device small.
//   - REAR POD: behind the ear. Houses the XIAO board, battery and buzzer
//     (placeholder for the eventual bone-conduction transducer). Behind-
//     the-ear is where hearing aids and BTE headphones put their bulk for
//     exactly this reason — it's already physically "spoken for" on a
//     normal face, and hair covers it.
//   - The camera ribbon runs along the temple arm between the two. Route
//     it under the arm or tuck it along the top edge; a dab of removable
//     adhesive at one or two points is enough for a prototype.
//
// The temple channel is cut THROUGH the pod body rather than bolted
// underneath it, so the channel ceiling and the cavity floor share one
// wall. That's worth ~5mm of height versus stacking a separate clip.
//
// Printer: Snapmaker U1, 270x270x270mm, standard FDM. WALL and CLEARANCE
// assume a 0.4mm nozzle — adjust those two first if your profile differs.
//
// !! MEASURE BEFORE PRINTING !!
// TEMPLE_* must match the actual glasses you're clipping onto, and the
// CAM_*/XIAO_* values must match your actual parts. Everything else
// follows from those. Print ONE fit-test piece (part="fit_test") before
// committing to a full pod — it's a 3-minute print that will save you a
// wasted hour.
//
// PLACEHOLDER SIZES: no touch sensor, amp, or battery sourced yet (team
// has the Freenove Ultimate Starter Kit + XIAO Sense only). Battery and
// buzzer cavities are sized for common off-the-shelf parts so this prints
// and test-fits NOW; tighten them once real parts arrive.
//
// Render each printable part:
//   openscad -o front_base.stl -D 'part="front_base"' vocalens_pod.scad
//   openscad -o front_lid.stl  -D 'part="front_lid"'  vocalens_pod.scad
//   openscad -o rear_base.stl  -D 'part="rear_base"'  vocalens_pod.scad
//   openscad -o rear_lid.stl   -D 'part="rear_lid"'   vocalens_pod.scad
//   openscad -o fit_test.stl   -D 'part="fit_test"'   vocalens_pod.scad

/* [Print settings] */
WALL = 1.6;        // 4 perimeters at 0.4mm nozzle — don't go below 1.2
CLEARANCE = 0.3;   // fit tolerance between mating FDM parts
EPS = 0.01;        // overlap to avoid coplanar faces in unions
EDGE_RADIUS = 1.0; // outer vertical-corner rounding, softens the "square
                    // box" look. Must stay comfortably under WALL or the
                    // rounding arc eats into the cavity at the corners.
$fn = 48;

// A rectangle rounded on its vertical corners only (top/bottom stay flat) —
// cheap, and doesn't risk collapsing thin lids the way rounding every edge
// of a 1.6mm-thick slab would. Used for every outer shell in this file so
// the pods read as a soft-cornered bar rather than a printed brick.
module rounded_prism(l, w, h, r) {
  linear_extrude(height = h)
    offset(r = r)
      offset(delta = -r)
        square([l, w]);
}

/* [Temple arm — MEASURE YOUR ACTUAL GLASSES] */
TEMPLE_THICKNESS = 4.5;  // temple arm thickness (side to side), mm
TEMPLE_WIDTH = 6.0;      // temple arm width (top to bottom), mm
SNAP_GAP = 1.0;          // how much narrower the opening is than the arm

/* [Camera module — detached from the XIAO, on its FPC ribbon] */
// The OV2640 module on the Sense expansion unclips from its FPC connector
// and can sit on its own. MEASURE YOURS — these are generous placeholders.
CAM_LEN = 11;   // along the temple
CAM_WID = 11;   // across (this is what sets front-pod width)
CAM_HGT = 7;    // protrusion from the temple

/* [XIAO ESP32S3 Sense board] */
// Bare XIAO is ~21 x 17.5mm.
XIAO_LEN = 23;
XIAO_WID = 19;
// XIAO_HGT: the full board+camera STACK height, kept for the legacy
// single-pod/reference variants that still stack the camera on top of the
// board. The committed build (frontboard_base) does NOT stack them -- see
// XIAO_THICK below.
XIAO_HGT = 8;
// XIAO_THICK: the board's OWN profile only (PCB + onboard components,
// e.g. the USB connector) with the camera NOT included -- used when the
// camera sits beside the board instead of on top of it. MEASURE YOURS;
// this is a placeholder.
XIAO_THICK = 5;

/* [Battery placeholder — common 3.7V 1S LiPo, e.g. 602030] */
BATT_LEN = 30;
BATT_WID = 20;
BATT_HGT = 6;

/* [Build variant] */
// COMMITTED BUILD for this event: ONE pod holding everything, using only
// parts in the Freenove kit + XIAO Sense. No purchases, no shipping risk.
// The two-pod split and bone conduction are documented as future
// upgrades (see hardware/README.md) but are NOT part of this build.
SINGLE_POD = true;

/* [Audio output — pick one] */
// Kept false for this build: the kit speaker is what's actually on hand.
// BONE_CONDUCTION=true still renders correctly (see cad/bone_conduction/)
// as a documented future-upgrade reference for the pitch deck, but it is
// not part of the committed build since it requires an external part.
BONE_CONDUCTION = false;

/* [Speaker — the round speaker included in the Freenove kit] */
// MEASURE YOURS. Kit speakers are typically 20-28mm diameter, 5-8mm deep.
SPKR_DIA = 28;
SPKR_HGT = 6;

/* [Bone-conduction transducer — e.g. Adafruit ADA1674] */
// Mounts OUTSIDE the cavity, on the inner face, so these dimensions set
// the mounting pad, not internal volume.
BC_LEN = 21.5;
BC_WID = 14.5;
BC_HGT = 8;

/* [Audio amp — the kit's "Audio Converter & Amplifier" module] */
// MEASURE YOURS. Small I2S breakout, typically ~22 x 16 x 4mm.
AMP_LEN = 22;
AMP_WID = 16;
AMP_HGT = 5;

part = "layout"; // front_base | front_lid | rear_base | rear_lid | fit_test | layout

// Derived: the temple channel sits at the bottom of the pod body
CH_H = TEMPLE_THICKNESS + CLEARANCE;   // channel height
CH_W = TEMPLE_WIDTH + CLEARANCE;       // channel width
// Pod width is driven by whatever it has to hold, never by the channel
// alone — a pod narrower than its own contents silently won't fit them.
function body_w(content_w) = max(CH_W, content_w) + 2 * WALL;

// ---------------------------------------------------------------------
// WHICH AXIS IS WHICH, WHEN WORN (read this before changing any module
// below):
//   X (length)   — along the temple arm, front to back.
//   Y (BODY_W, driven by "content_w" below) — the arm's TOP-TO-BOTTOM
//     axis. When the pod is clipped on, growing this axis pushes the pod
//     UP into the scalp/hair and DOWN toward the ear. KEEP THIS SMALL —
//     pass a component's THICKNESS here, never its footprint.
//   Z (cav_h)    — the arm's SIDE-TO-SIDE axis, i.e. straight out away
//     from the head. There is real clearance here. Pass a component's
//     larger footprint dimension here.
// Getting content_w and cav_h backwards is exactly what made the first
// version of this design rest its bulk on top of the wearer's head
// instead of out to the side of it.
// ---------------------------------------------------------------------

// ---------------------------------------------------------------------
// Pod body: one solid block with the temple channel subtracted from the
// bottom and a component cavity opened in the top.
//   length     — along the temple arm
//   cav_h      — component cavity height
//   extras()   — additional subtractions (ports, holes), applied in the
//                body's own coordinate space
// ---------------------------------------------------------------------
module pod_body(length, cav_h, content_w) {
  BODY_W = body_w(content_w);
  total_h = WALL + CH_H + WALL + cav_h + WALL;
  difference() {
    rounded_prism(length, BODY_W, total_h, EDGE_RADIUS);

    // temple channel, running the full length, open at the bottom face
    translate([-EPS, WALL, WALL])
      cube([length + 2 * EPS, CH_W, CH_H]);

    // slot from channel down through the bottom face, narrower than the
    // arm so the pod snaps on and grips by spring tension
    translate([-EPS, WALL + SNAP_GAP / 2, -EPS])
      cube([length + 2 * EPS, CH_W - SNAP_GAP, WALL + 2 * EPS]);

    // component cavity, open at the top face
    translate([WALL, WALL, WALL + CH_H + WALL])
      cube([length - 2 * WALL, BODY_W - 2 * WALL, cav_h + WALL + EPS]);

    children();
  }
}

// cavity floor height, for positioning ports relative to the cavity
function cav_floor() = WALL + CH_H + WALL;
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

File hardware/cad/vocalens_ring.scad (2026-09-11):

// ============================================================================
// Vocalens — ring-mount enclosure  (v2, replaces the integrated-clip design)
//
// WHAT CHANGED FROM vocalens_pod.scad
//   v1 baked the temple clip into the pod base, so the pod was sized to one
//   exact temple arm and needed a fit_test / SNAP_GAP tuning loop.
//   v2 splits the two jobs:
//     * temple_ring()  — soft TPU collar. STRETCHES onto the arm: the opening
//       is undersized and the wall is thin, so one ring grips a wide range of
//       arms with no tuning print.
//     * pod_base()     — rigid PETG box. Never touches the glasses. Carries a
//       dovetail SLOT that drops onto the ring's rail.
//
//   Consequence: you print pods once. If a ring doesn't grip, you reprint a
//   ~10 minute ring, not a 3-hour pod with electronics glued into it.
//
// WHICH AXIS IS WHICH, WHEN WORN (unchanged from v1 — read before editing):
//   X (length)  — along the temple arm, front to back.
//   Y (vert)    — the arm's TOP-TO-BOTTOM axis. Growing this pushes the pod
//     UP into the scalp and DOWN toward the ear. KEEP SMALL. Pass a
//     component's THICKNESS here, never its footprint.
//   Z (out)     — straight out, away from the head. Real clearance here.
//     Pass a component's larger footprint here.
//
// INTERLOCK DIRECTION
//   Male dovetail RAIL on the ring (soft TPU), female SLOT in the pod (rigid
//   PETG). Soft-into-hard is deliberate: the TPU rail compresses slightly on
//   assembly, so the joint self-tightens and never rattles, and a small print
//   tolerance error is absorbed by the soft part instead of jamming.
//   The rail is wider at the top than at its neck, so the pod cannot lift
//   off — it only releases by sliding along the arm.
//
// MATERIALS
//   temple_ring  -> TPU  (soft; 15-20% gyroid infill, 2 perimeters)
//   pod bases    -> PETG (rigid)
//   pod lids     -> PETG (rigid)
// ============================================================================

// ---------------------------------------------------------------- tolerances
WALL        = 1.6;   // 4 perimeters at 0.4mm nozzle — don't go below 1.2
CLEARANCE   = 0.3;   // fit tolerance between mating FDM parts
EPS         = 0.01;
EDGE_RADIUS = 1.0;
$fn         = 48;

// ------------------------------------------------------------------ the ring
// STRETCH FIT, like a hair tie — not a loose sleeve.
//
// The opening is deliberately SMALLER than the temple arms it has to fit. A
// thin TPU wall in tension grips far harder, and over a far wider range, than
// a generous opening relying on bumps to take up slack. So the rule here is
// the opposite of the usual one: if it doesn't grip, make the opening
// SMALLER or the wall THINNER — never larger.
//
// Nominal below is undersized against a typical arm (~4-5mm thick, ~8-9mm
// tall). It stretches up comfortably; a very slim arm is the case that goes
// loose, which is the safer way round to be wrong.
RING_LEN      = 14;   // X — how much of the arm the ring covers
// HOW FAR UNDERSIZED — there is a right amount, and it is not "as much as
// possible". TPU grips hardest at roughly 20-30% strain. Past that it stops
// being a press fit and becomes a fight: the ring will not go on at all, or it
// goes on stretched so far that it takes a permanent set and grips worse than
// a milder one would have. An opening of 5.0 x 2.2 was tried against a real
// arm and could not be fitted — that is around 120% strain on the thin axis.
//
// So aim for about 75-85% of the arm's actual section, and measure the arm
// rather than assuming. Print the ladder below if you have not measured.
RING_IN_VERT  = 7.5;  // Y — vs an arm of roughly 9-10mm height
RING_IN_OUT   = 3.4;  // Z — vs an arm of roughly 4-5mm thickness
RING_WALL     = 1.2;  // thin on purpose: 3 perimeters, stretches easily.
                      // Thicker walls fight you on every fit.


// The rail must NOT stretch with the rest of the ring, or the pod joint
// changes size depending on whose glasses it's on. So the wall directly under
// the rail is locally thickened: the thin side walls do all the stretching
// while the rail footprint stays dimensionally stable.
RAIL_BOSS_T   = 1.4;  // extra wall thickness under the rail only

// -------------------------------------------------------------- the dovetail
// Trapezoid, WIDER AT THE TOP so the pod can't be pulled straight off.
DT_NECK   = 5.0;   // width at the root (narrow)
DT_HEAD   = 8.0;   // width at the top (wide)
DT_HEIGHT = 4.0;
// The pod's slot is cut with CLEARANCE (0.3) of slack, so the rail must be
// grown by MORE than that or the joint is a slip fit and the pod rattles —
// the numbers must be read together, not tuned separately.
//   net interference per face = DT_SQUISH - CLEARANCE = 0.15mm
// which TPU takes up by compressing. Raise it if the pod is still loose;
// lower it if the pod will not slide on by hand.
DT_SQUISH = 0.45;

// Measured on printed parts: the joint was too tight to assemble, so the slot
// gets this much more on top of CLEARANCE. It is applied to the SLOT ONLY, not
// to the rail, because the rail's size is also what grips — shrinking the rail
// instead would loosen the joint twice over.
//   net per face = DT_SQUISH - CLEARANCE - DT_SLOT_EXTRA
// which is now slightly negative, i.e. a sliding fit rather than a press fit.
// That is deliberate: the TPU ring is soft enough that friction down the length
// of the rail still holds the pod, and a joint that cannot be assembled is
// worth nothing.
DT_SLOT_EXTRA = 0.5;

// ------------------------------------------------------------- component box
// MEASURE YOUR OWN PARTS AND CHANGE THESE BEFORE PRINTING.
//
// These are nominal figures, not measurements of the parts in your kit, and
// every pod dimension is derived from them — so an error here is an error in
// the print. SPKR_DIA is the one to check first: it alone sets the rear pod's
// outward bulk (28mm of a 31mm pod), so if your speaker is smaller than 28mm
// the whole rear pod shrinks with it for free.
CAM_LEN = 11; CAM_WID = 11; CAM_HGT = 7;
XIAO_LEN = 23; XIAO_WID = 19;
XIAO_THICK = 5;    // board profile WITHOUT the camera (PCB + USB shell)

// HEADERS_FITTED — set true if you soldered the 2x7 pin headers onto the board.
//
// This matters more than it looks. Headers plus a pushed-on jumper socket add
// roughly 10mm to the board's profile, and that profile drives the pod's
// VERTICAL extent — the axis that runs into the wearer's scalp and ear, where
// there is almost no clearance. Bare board gives a 10.2mm pod; with headers it
// is about 19mm, which is close to the bulk the whole two-pod split was meant
// to avoid.
//
// So: headers are excellent for bench testing (everything just plugs in, no
// iron, and you can unplug to debug). For the pod that goes on a face, either
// print the taller variant and accept the bulk, or remove the headers and
// solder wires flat to the pads.
HEADERS_FITTED  = false;
HEADER_STACK    = 16;   // board + header plastic + mated jumper socket
XIAO_PROFILE    = HEADERS_FITTED ? HEADER_STACK : XIAO_THICK;


// WIRE_ROOM — headroom above the tallest component for wire to lie in and,
// more importantly, to TURN in.
//
// A jumper socket pushed onto a header leaves along the pin axis, which is the
// vertical (Y) axis here, and then has to turn 90 degrees to run along the pod.
// With no allowance the wire is forced flat against the lid the moment it
// leaves the socket, and the bend loads the solder joint rather than the wire.
// Stranded jumper wire bends tightly without harm; the joint it is pulling on
// does not.
//
// Bends of any size happen in the X-Z plane, where there is 19mm (front) and
// 28mm (rear) to work in, so this only has to cover the initial turn.
WIRE_ROOM = 2;
SPKR_DIA = 28; SPKR_HGT = 6;
AMP_LEN = 22; AMP_WID = 16; AMP_HGT = 5;
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

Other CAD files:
hardware/cad/final_rearaudio_base.stl
hardware/cad/final_frontboard_lid_HEADERS.stl
hardware/cad/final_rearaudio_lid.stl
hardware/cad/FINAL_tpu_rings.stl
hardware/cad/FINAL_petg_plate_XIAOSOCKETS_AMPFLAT.stl
hardware/cad/FINAL_tpu_rings_LADDER.stl
hardware/cad/final_temple_ring.stl
hardware/cad/fit_test.stl
hardware/cad/frontboard_base.stl
hardware/cad/frontboard_lid.stl
hardware/cad/rearaudio_base.stl
hardware/cad/rearaudio_lid.stl
hardware/cad/single_base.stl
hardware/cad/single_lid.stl
hardware/cad/single_plate.stl
hardware/cad/split_plate.stl

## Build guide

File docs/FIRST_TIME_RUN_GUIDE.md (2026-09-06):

# Running Vocalens for the first time

This is a start-to-finish guide for someone who has never done any of this
before — installing PlatformIO, starting the server, flashing the board, and
taking a first camera reading. Follow it in order.

## Before you start: two windows

You'll need two terminal/editor windows open side by side for the whole
session:

1. **A terminal window** — this runs the Python server (`uvicorn`). Leave it
   open the entire time; it's your main log of what the board is sending.
2. **A VS Code window with PlatformIO** — this is where you edit, build, and
   upload the firmware, and where the Serial Monitor lives.

Keep both visible if you can — when you take a photo later, you'll want to
watch both at once.

## Installing PlatformIO

1. Install [VS Code](https://code.visualstudio.com/) if you don't have it.
2. Open VS Code → Extensions (the icon on the left sidebar, or `Ctrl+Shift+X`).
3. Search for **"PlatformIO IDE"** and click Install.
4. Wait for it to finish (it installs its own Python environment in the
   background — this can take a few minutes the first time).
5. Restart VS Code when it asks you to.
6. **Important**: don't open the whole repo folder in VS Code. Open the
   `firmware` folder specifically (File → Open Folder → select `firmware`).
   PlatformIO only shows its toolbar (the row of icons at the very bottom of
   the window) when `platformio.ini` is at the top level of what's open — if
   you open the repo root instead, that toolbar won't appear and nothing
   will seem to work.

## 1. Starting the server

Run this from a fresh terminal, in the `server` folder.

```
cd server
python -m venv .venv
.venv\Scripts\activate
pip install -r requirements.txt
uvicorn main:app --host 0.0.0.0 --port 8000
```

(`.venv\Scripts\activate` is the Windows command — you should see `(.venv)`
appear at the start of your prompt once it's worked.)

You should see `Uvicorn running on http://0.0.0.0:8000` and nothing else —
leave this terminal open and running for the rest of the session. Every
request the board makes will show up here as a new log line, so keep an eye
on it.

### Problems that came up getting here, and how they were fixed

These are worth knowing in case you hit the same ones:

- **`pip install` fails trying to build Pillow or pydantic from source**
  (mentions `link.exe not found` or `maturin failed`) — this happens when
  the venv's Python is too new for the exact package versions pinned in
  `requirements.txt`. Already fixed in this repo's `requirements.txt`
  (`Pillow>=11.0.0`, `pydantic>=2.10.0`), so a fresh `pip install` shouldn't
  hit this — but if it does, those are the two lines to loosen.
- **`python -m venv .venv` — "Unable to create process...system cannot find
  the file specified"** — happened when trying to force a specific Python
  version (e.g. `py -3.13`) that wasn't actually installed properly. Fixed
  by just using plain `python -m venv .venv` and letting it use whatever
  version is on your PATH.
- **`pip install -r requirements.txt` → "Could not open requirements file"**
  — means your terminal isn't `cd`'d into the `server` folder yet. Run
  `cd server` first, and check with `dir` that `requirements.txt` is
  actually listed there.
- **Server crashes on startup with a `pyzbar`/`libzbar-64.dll not found`
  error** — this is the barcode-scanning library, and it's broken on some
  Windows setups. It's not needed for the main camera+question flow, and
  `server/main.py` already catches this error and disables barcode scanning
  gracefully instead of crashing — you should just see a warning logged, not
  a crash. If you ever see the server actually crash on this, it means that
  fix isn't in your copy of `main.py`.
- **The README mentions `.env.example` and `ANTHROPIC_API_KEY`/
  `OPENAI_API_KEY`** — this is out of date. All you actually need is one
  file, `server/.env`, containing a single line:
  ```
  OPENROUTER_API_KEY=your-key-here
  ```
  Every model call (vision, speech-to-text, text-to-speech) goes through
  OpenRouter now, so this one key is all that's required.

## 2. Using the secrets file

The firmware needs your WiFi details and your computer's IP address, kept in
a file that's never committed to git (so credentials don't leak).

1. In `firmware/src/`, find `secrets.h.example`.
2. Copy it and rename the copy to `secrets.h`, in the same folder.
3. Open `secrets.h` and fill in:
   ```
   #define WIFI_SSID "your-wifi-name"
   #define WIFI_PASSWORD "your-wifi-password"
   #define SERVER_HOST "192.168.x.x"
   #define SERVER_PORT 8000
   ```
4. To find `SERVER_HOST`: open a new terminal on the computer running the
   server and run `ipconfig`. Look under "Wireless LAN adapter Wi-Fi" for
   **IPv4 Address** — it'll look like `192.168.x.x` or `10.x.x.x`. That's
   the value to put in `SERVER_HOST`.

**This IP address changes** if you reconnect to WiFi or restart your
computer — if the board suddenly can't reach the server after a break,
re-check `ipconfig` and update `secrets.h` if it's changed.

If the board can't reach the server at all, also check that Windows
Firewall isn't blocking it — add an inbound allow rule for
`server\.venv\Scripts\python.exe` on Private networks.

## 3. Connecting and uploading via PlatformIO

1. Plug the board in via USB.
2. With the `firmware` folder open as your project root, look at the bottom
   status bar in VS Code — that's the PlatformIO toolbar.
3. Click the checkmark icon to **Build** — this compiles the code without
   uploading, so it's a fast way to check for errors first.
4. Click the right-arrow icon to **Upload** — this flashes the compiled code
   onto the board. Wait for `SUCCESS` in the terminal output at the bottom.
5. Click the plug icon to open the **Serial Monitor** — this is how the
   board talks back to you (115200 baud, already set as the project
   default). You should see boot messages, including `WiFi connected`.

By default this builds the real firmware (`main.cpp`). PlatformIO also has
two other environments in this project for testing individual parts in
isolation — click the environment name in the same toolbar to switch:
- `selftest` — full hardware diagnostic (see below)
- `beeptest` — makes the speaker beep once a second, for isolating
  speaker/amp wiring issues
- `ledblink` — blinks the onboard LED and one on pad D10, the simplest
  possible "does the board run my code at all" check

Switch back to the default environment before flashing the real firmware
again — only one of these can be compiled and running at a time.

## 4. Running the selftest

Use this to check PSRAM, camera, touch pad, I2S audio, WiFi, and server
reachability all in one go, before trying the full pipeline.

1. In the PlatformIO toolbar, switch the environment to `selftest`.
2. Build → Upload → open the Serial Monitor.
3. It runs through each check automatically and prints `PASS`/`FAIL` for
   each one, with notes if something failed.
4. Switch the environment back to the default (`seeed_xiao_esp32s3`) before
   flashing the real firmware again.

## 5. Running the camera test

This is the full bench-test flow: touch the coin, type a question, get a
text answer back, with a real photo taken along the way.

Make sure the server (step 1) is running and the board has been flashed
with the real firmware (not `selftest`) and shows `WiFi connected` in the
Serial Monitor first.

1. Open the **Serial Monitor** in PlatformIO if it isn't already open.
2. **Touch the coin.** An input box should appear at the top of the Serial
   Monitor panel.
3. Type your question into that input box (e.g. "what is this?") and press
   **Enter**. You have 15 seconds to do this before it falls back to a
   default question.
4. Wait for the answer. The board captures a photo and sends it to the
   server — both terminals should show activity:
   - The **server terminal** logs the incoming request and shows
     `Saved capture: ...jpg`.
   - The **PlatformIO Serial Monitor** prints the answer once it comes
     back, under a line that reads `===== ANSWER =====`.
5. **To see the actual photo**, look in `server/captures/` — every photo the
   board sends gets saved there automatically, named with a timestamp. Open
   the most recent one to see exactly what the board captured and sent.

## 6. Changing the model, image resolution and compression

### Changing the vision model

The model that answers questions about the photo is set in `server/.env`:

```
VISION_MODEL=minimax/minimax-m3:free
```

Change the value and restart `uvicorn` (`Ctrl+C` in the server terminal,
then run the `uvicorn` command again) to pick a different model — any
vision-capable model available on [OpenRouter](https://openrouter.ai/models)
will work, referenced by its OpenRouter model ID (the
`provider/model-name` format shown on its page there). If the line isn't in
`.env` at all, it just uses the default shown above.

Free-tier models (ID ends in `:free`) are the slowest and least accurate
option — they're what's being used now to avoid burning credits during
testing, but a paid model is the single biggest lever for both faster
answers and better accuracy, if you have credit available.

### Changing image resolution and compression

Both are set in `setupCamera()` in `firmware/src/main.cpp`:

```cpp
config.frame_size = FRAMESIZE_SXGA; // 1280x1024
config.jpeg_quality = 9;            // lower number = less compression
```

- **`frame_size`** controls resolution. Common options, smallest to
  largest: `FRAMESIZE_VGA` (640x480), `FRAMESIZE_SXGA` (1280x1024),
  `FRAMESIZE_UXGA` (1600x1200 — the largest this sensor supports). Higher
  resolution gives the vision model more detail to work with (useful for
  small print) but makes for a bigger file, which takes longer to upload
  over WiFi and adds to the overall response time.
- **`jpeg_quality`** controls compression, on a scale of roughly `0`–`63` —
  counterintuitively, a **lower** number means **less** compression and a
  **higher-quality** image (and a bigger file). `9` is fairly high quality;
  going up towards `20`+ trades detail for a smaller, faster-uploading file.

After changing either value, rebuild and reflash for it to take effect, and
check `server/captures/` to see the actual result.

## 7. A few other things worth knowing

- **No speaker audio yet** — this bench-test flow deliberately prints the
  answer as text instead of playing it aloud. The speaker/amp still has an
  unresolved static/faint-audio issue; `beeptest` (see step 3) is there to
  help isolate that separately if you come back to it.
- **Touch sensitivity not yet fully calibrated** — `pins.h`'s
  `TOUCH_THRESHOLD` is still a placeholder value, not a number taken from a
  real `selftest` run on your actual coin/wiring. If the coin ever stops
  triggering reliably or fires on its own, re-run `selftest`, note the
  reported touch reading, and update `TOUCH_THRESHOLD` in `pins.h` to match.
- **Camera orientation** — if the photo in `server/captures/` looks flipped
  or mirrored, `CAMERA_VFLIP` and `CAMERA_HMIRROR` in `pins.h` control this.
  Only one of the two should usually be set to `1` for a true mirror-image
  fix (both set to `1` together instead rotates the image 180°).
- **Photo blur** — this camera has a fixed-focus lens; it needs the subject
  roughly 15–30cm away to focus properly, and it has no image stabilisation,
  so keep the board steady for a moment when you trigger it.
- **Answer accuracy and speed** — the vision model in use
  (`VISION_MODEL` in `server/.env`, defaulting to a free-tier OpenRouter
  model) is the main factor in both how accurate answers are and how long
  they take to come back. A wrong answer is often the photo being blurry or
  the free model, not a bug in the code.
- **Full troubleshooting reference** — `docs/BENCH_TEST_PIPELINE.md` has a
  more detailed list of problems hit and fixes that worked, if something
  here doesn't cover what you're seeing.

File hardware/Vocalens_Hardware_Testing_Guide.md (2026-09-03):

# Vocalens Hardware Testing Guide — From Zero

This is a complete, from-scratch guide to testing the physical electronics your
teammate built, written for someone who has never done electronics before.
Every concept is explained before it's used. Follow it top to bottom, in order.

**Ground rule for the whole guide:** if a step ever says "power OFF," that
means the USB cable is physically unplugged from the board. Not "the code
isn't running" — unplugged. Several early steps exist specifically to catch
problems *before* you ever apply power, because a wiring mistake found before
power is a five-minute fix, and the same mistake found after power can
destroy a $20+ board in under a second.

---

## Part 0 — What is this thing, in plain terms

### What's in the GitHub repo

The repo is just a folder of files your team has been working from. Three
folders matter to you:

- **`firmware/`** — the program that will eventually run *on* the small
  circuit board itself (the "brain" of the glasses). Written in C++.
- **`server/`** — a separate program that runs on a laptop, not on the board.
  It receives a photo, asks an AI to read it, and sends back an audio reply.
  You don't need this for hardware testing, but you'll use a small piece of
  it later (Stage 6b).
- **`hardware/`** — instructions and 3D-printable files for the physical
  case ("pods") the electronics sit inside. Background reading, not part of
  electrical testing.

Inside `firmware/`, there's a file called **`selftest.cpp`**. This is a
*diagnostic* program — a separate, simpler program from the "real" one, whose
only job is to test each piece of the hardware one at a time and tell you in
plain text whether it works. This is the single most useful file for what
you're about to do, and most of this guide is built around using it.

### What the physical build actually is

Picture a pair of glasses with two small plastic boxes clipped onto one arm
(temple), joined by a handful of thin wires:

- **Front box (near the hinge):** contains the "brain" (a small circuit
  board) and a tiny camera. Also has a coin or screw-head glued to it that
  acts as a touch button.
- **Back box (behind the ear):** contains an amplifier chip and a small
  round speaker.
- **Wires between the two boxes:** carry power and an audio signal from the
  front box to the back box.

### The components, one at a time

**XIAO ESP32S3 Sense (the "board" or "microcontroller")**
This is a tiny computer, about the size of a large postage stamp. Think of
it as a very small, very limited laptop: it can run a program (the
firmware), talk to a camera, listen to a microphone, connect to WiFi, and
send electrical signals out through small metal contact points called
**pins**. It has no screen or keyboard of its own — you talk to it by
plugging it into your laptop with a USB cable.

**Camera**
A small image sensor on a short ribbon (flat flexible strip) that plugs
into the board. It takes photos when the firmware tells it to.

**Amplifier ("amp") module**
Electrical signals from the board are very weak — far too weak to move a
speaker cone and make sound you can hear. The amp's only job is to take
that weak signal and boost it into something strong enough to drive the
speaker. Think of it like a megaphone for an electrical signal.

**Speaker**
Converts the amplified electrical signal into actual sound waves you hear.

**Touch pad (a coin or screw head)**
Just a piece of bare metal, wired to one pin on the board. The board can
sense when a finger is touching a piece of metal connected to it (more on
this in Stage 6). There's no separate "touch sensor" component — the metal
disc *is* the sensor, and the board's built-in capability does the work.

**Jumper wires**
Ordinary short wires with connectors on the ends, used to link components
together without soldering. Some of your teammate's connections are
soldered (permanent) and some may be jumper wires (removable, pushed onto
pins) — you'll figure out which is which in Stage 1.

---

## Part 1 — Concepts you need before touching anything

Read this whole part once, even the bits that seem irrelevant right now.
You'll be referred back to specific paragraphs throughout the guide.

### Electricity, in one analogy

Electricity is easiest to understand as water flowing through pipes.

- **Voltage** is like water pressure — how hard the electricity is being
  "pushed." Measured in **volts (V)**. Your board runs on **3.3 volts**
  (often written "3V3"), which is low — nowhere near dangerous to a person
  — but it *can* instantly destroy small electronic components if
  connected wrong, the way a garden hose at the wrong pressure can burst a
  cheap fitting even though it can't hurt your hand.
- **Current** is like the actual flow rate of water — how much electricity
  is moving. Measured in **amps (A)**, or for small electronics, in
  thousandths of an amp, **milliamps (mA)**.
- **Resistance** is like a narrowing in the pipe that restricts flow.
  Measured in **ohms (Ω)**. Wires have very low resistance (electricity
  flows through them easily, on purpose). Components like resistors add
  resistance on purpose to control how much current flows.
- **A circuit** is a complete loop the electricity can flow around — like a
  loop of pipe with a pump. Electricity only flows if the loop is
  complete. If you cut the loop anywhere, nothing flows anywhere in it.

### Ground / GND

Every circuit needs a "return path" — somewhere the electricity flows back
to after doing its job, to complete the loop. In small electronics, this
return path is called **ground**, abbreviated **GND**. It's not literally
connected to the earth; it's just the agreed "zero volts" reference point
that everything else in the circuit is measured against. Every single
component in this build — the board, the amp, the speaker circuit — shares
one common GND. If GND isn't properly connected somewhere, that whole
branch of the circuit won't work, even if everything else looks fine.

### Short circuit

A short circuit is when electricity finds an *unintended* path between two
points that skips around the components that are supposed to control or
use it — most dangerously, a direct wire-to-wire connection straight
between power (3V3) and GND with nothing in between to limit the flow.

Using the water analogy: it's like connecting the output of a water pump
directly back to its own intake with a wide-open pipe and nothing in the
loop to do useful work. The pump doesn't do anything useful, and it can
overheat trying to push against zero resistance.

In electronics, a short from power to ground means current has almost
nothing limiting it, so it can spike very high, very fast. This produces
heat, and can permanently destroy the board or amp in under a second, with
no warning. **This is the single most important failure mode we're
checking for before you ever plug in power**, because unlike most mistakes,
a bad short can happen the instant power is applied — there's no "test it
carefully and back off if something seems wrong," it can already be too
late by the time you notice.

### Power, VCC / 3V3

"Power" just means a voltage source available for a circuit to use. On this
board, you'll see a pin actually labeled **3V3** — this is the board's
regulated 3.3-volt power output, and it's what your amp draws its power
from. (Some boards label this pin "VCC" instead; on the XIAO board used
here, it's specifically labeled 3V3, and there's a separate 5V pin you are
**not** using for this connection.)

### GPIO, signal, input/output

**GPIO** stands for "General Purpose Input/Output" — a pin on the board
that firmware can use either to:
- **read** an electrical state from the outside world (input) — e.g.
  "is this touch pad being touched right now?", or
- **send** an electrical state out to the outside world (output) — e.g.
  "tell the amp module what audio data to play right now."

A **signal** just means "information carried as a changing voltage on a
wire," as opposed to power, which is just there to run something. The
three wires going to your amp module (BCLK, LRC, DIN — explained in Part
3) are all signal wires, not power wires — they carry rapidly changing
audio data, not steady power.

### Pull-up (mentioned for completeness)

A pull-up resistor is a small resistor that gently holds a pin at a known
voltage (usually 3.3V) when nothing else is actively driving it, so a
floating/undefined input doesn't produce random, meaningless readings. You
won't need to add one yourself in this build — the board's internal
circuitry and firmware settings already handle this for the touch pin and
any button — but it's worth knowing the term since it may come up if
something behaves inconsistently.

### Microcontroller, firmware, code

A **microcontroller** is the small computer chip on the board (inside the
XIAO). **Firmware** is the specific program that runs directly on a
microcontroller — as opposed to an app on your phone or a program on your
laptop, firmware runs with no operating system, directly on the bare chip.
"Code" and "firmware" are used interchangeably here. You don't need to
write any of it — it already exists in the repo — but you do need to
*send* it to the board, which is called **flashing** or **uploading**.

### Serial communication / USB

**Serial communication** means sending information one bit at a time over
a wire, in order — as opposed to sending many bits at once side-by-side.
It's the standard way small microcontrollers "talk" back to a computer.
When you plug the board into your laptop with a **USB** cable, two things
happen over that same cable: (1) power is supplied to the board, and (2) a
serial communication channel opens, letting your laptop send the firmware
to the board, and letting the board send text messages back to your laptop
(this is how you'll "hear" the board tell you what's working, via a window
called the **Serial Monitor**).

### Multimeter (full explanation in Part 4 — flagging it here since it's used constantly)

A handheld tool with two probes that measures voltage, resistance, and
continuity (whether two points are electrically connected). This is your
main testing instrument for everything before you write or run any code.

### Breadboard (not really used in this build, mentioned for completeness)

A breadboard is a reusable plastic board with holes for temporarily
plugging in components and wires without soldering, for prototyping. Your
build appears to be a mix of permanent solder joints and some push-on
jumper-wire connections directly onto the board — no breadboard is
involved. If you ever do see one in this project, treat it as a temporary
bench-test rig, not part of the final wearable.

---

## Part 2 — Wiring reference table

This is drawn directly from your teammate's own wiring documentation
(`wiring_guide.html`, `solder_card.html`) and cross-checked against the
actual firmware pin definitions in `firmware/src/pins.h`. All three sources
agree with each other, which is a good sign — but **none of them is a
photo of the real board**, so before you rely on this, do the physical
verification described in Stage 1.

**Important labeling gotcha, stated up front:** the tiny text printed on
the board next to each pin (the "silkscreen," e.g. `D8`) is *not* the same
number as the GPIO number used in the code (e.g. `GPIO 7`). They refer to
the same physical pin, but by two different naming systems. Always wire
and verify by the **printed pad label** on the board, since that's what
your eyes can actually check.

| From (board pad, printed label) | GPIO number (used in code) | To | Wire colour (per docs) | Purpose | What it carries | Check |
|---|---|---|---|---|---|---|
| `3V3` | — (power pin, no GPIO number) | Amp `VIN` | Red | Powers the amp | Steady 3.3V power | Confirm it's `3V3`, not the nearby `5V` pin |
| `GND` | — (ground pin) | Amp `GND` | Black | Shared ground / return path | 0V reference | Must be connected — nothing works without this |
| `D8` | `GPIO 7` | Amp `BCLK` (also labeled `SCK` on some amps) | Yellow | I2S bit clock — timing pulse for the audio data | Rapidly pulsing digital signal | Not power — should read as a signal, not a steady voltage |
| `D9` | `GPIO 8` | Amp `LRC` (also labeled `WS`) | Green | I2S word select — tells the amp left vs. right audio channel | Digital signal | — |
| `D10` | `GPIO 9` | Amp `DIN` | Blue | I2S data — the actual audio samples | Digital signal | — |
| `D2` | `GPIO 3` | Touch disc (coin/screw head) in front pod lid | White | Touch-sense input | Capacitive sensing signal | This is the *only* pin using this jack of wires — it does not connect to the amp at all |
| Amp `OUT+` / `OUT−` | — | Speaker's two terminals | (typically 2 unmarked wires) | Delivers amplified audio to the speaker | Amplified analog audio | Polarity does **not** matter here — a single speaker has no "wrong way round" |

**I2S**, mentioned above, is just the name of the standard these three
signal wires (BCLK/LRC/DIN) together implement for sending digital audio
between two chips. You don't need to understand how it works internally —
just that these three wires are a matched set and none of them carries
power.

**What is deliberately NOT connected, and should stay that way:**
- The board's `5V` pin — not used in this design.
- The board's `D0`, `D1`, `D3`(as touch, that's `D2`)... — i.e. any pad not
  in the table above should have nothing wired to it.
- On the amp module, any pins labeled `GAIN`, `SD`, or `SHUTDOWN` — these
  should be left completely empty. Connecting `SD`/`SHUTDOWN` to ground
  will silence the amp entirely, which looks exactly like a wiring fault
  but isn't one.

### How to physically identify things on the board

- **The board** is the smaller of the two boxes' main components — a green
  or blue rectangular circuit board roughly the size of a large postage
  stamp, with a USB-C socket (a small silver slot) at one end.
- **Pads/pins** are small silver-coloured rectangles along both long edges
  of the board, each with a tiny letter/number printed next to it. With
  the USB socket pointed away from you, one edge reads (top to bottom)
  `D0 D1 D2 D3 D4 D5 D6`, and the other reads `5V GND 3V3 D10 D9 D8 D7`.
  Use your phone's camera zoomed in if the print is too small to read.
- **Positive vs. negative / power vs. ground:** on this specific board,
  there's no ambiguity to resolve — the pins are individually labeled
  `3V3`, `5V`, and `GND` directly, rather than using generic + / − marks.
  Wire by the printed label, not by wire colour (wire colours in the docs
  are a convention your teammate chose, not something enforced by the
  hardware itself).
- **The camera** connects via a short, flat ribbon cable into a small
  black clip connector — you should NOT need to touch this unless it's
  come loose (see Stage 1).
- **The amp module** is a separate small board with its own pin labels
  printed on it (`VIN`, `GND`, `BCLK`/`SCK`, `LRC`/`WS`, `DIN`, and
  possibly `GAIN`/`SD`). Exact label wording can vary by manufacturer —
  the wiring guide already lists the common alternate names above.

### Where this could still be ambiguous — verify yourself

I don't have a photo of the actual soldered board, so I can't confirm:
- Which physical wire colour was actually used for which signal (your
  teammate may not have had all six specified colours available).
- Whether every connection was soldered directly to the pad, or whether
  some use small push-on jumper connectors.
- The exact model/brand of amp module, and therefore its exact pin
  labeling.

**Before Stage 1**, take a clear, well-lit photo of both pods with the
lids off, and compare what you see against the table above by *label*,
not colour. If a wire colour doesn't match what's in the table, that's not
automatically wrong — just note it and confirm where each wire actually
starts and ends by tracing it with your eyes (or the continuity test in
Stage 2, which is the reliable way to know for certain).

---

## Part 3 — Multimeter, taught from scratch

### What it is

A multimeter is a handheld box with a dial (or buttons) to select a mode,
a small screen, and two thin cables ending in metal probe tips — one red,
one black. It measures electrical properties by touching the two probe
tips to two points in a circuit.

### The two probe sockets

Most multimeters have 2–3 sockets to plug the probes into. For everything
in this guide, you only need:
- **Black probe → socket labeled `COM`** (common/ground reference).
  Always plug it here.
- **Red probe → socket labeled `V Ω mA` or similar** (the standard socket
  for voltage, resistance, and continuity). There is sometimes a
  *separate* socket for measuring large current, often labeled `10A` — you
  will **never** use that socket in this guide. Measuring current requires
  breaking open the circuit and putting the meter directly in the current
  path, which risks a short if done wrong, and this build doesn't need it.
  If your red probe is ever plugged into a current socket, unplug it and
  move it back to `V Ω mA` before doing anything else.

### The modes you need

Turn the dial (or press mode button) to select:

1. **Continuity mode** — usually shown as a small sound-wave symbol `)))`
   or a diode symbol. This mode makes the meter beep if the two probes are
   electrically connected to each other (even through a long path of
   wire), and stay silent if they are not. **This is your main tool for
   almost this entire guide.**
2. **DC Voltage mode** — usually shown as `V` with a straight/dashed line
   (as opposed to `V` with a wavy line, which is AC voltage — not used
   here). Set the range to something like 20V if your meter is manual
   range (auto-ranging meters handle this themselves). This measures the
   voltage *difference* between two points, without breaking the circuit
   open — you just touch both probes to two points while the circuit is
   powered.
3. **Resistance mode (Ω)** — you likely won't need this directly, since
   continuity mode already tells you what you need for this project, but
   it's the same probe setup as continuity.

### The critical difference: voltage vs. current measurement

- **Measuring voltage** = touching both probes to two points *without*
  cutting or opening the circuit. The meter sits "alongside" the circuit,
  sipping a tiny bit of current to sense the voltage, and doesn't disturb
  anything. This is safe to do on a powered circuit, and it's what you'll
  do in Stage 3.
- **Measuring current** = requires breaking the circuit open and forcing
  ALL the current to flow *through* the meter itself, in series. If you
  ever did this by mistake — e.g. by setting the dial to a current mode
  and then touching the probes across two points like you would for
  voltage — you create a short circuit through the meter, which can blow
  a fuse in the meter at best, and damage your board at worst.
  **You will not need to measure current anywhere in this guide.** I'm
  flagging this so that if you ever see a current-related mode on your
  dial (often marked `A` or `mA`), you know to avoid it here.

### Continuity testing — step by step

This must always be done with **the circuit completely powered off** (USB
unplugged). Testing continuity on a powered circuit can give misleading
readings and, more importantly, some meters can be damaged by voltage
present in continuity mode.

1. Set the dial to continuity mode (`)))`).
2. Touch the two probe tips together, away from the circuit. You should
   hear a beep and see a reading near `0` (near-zero resistance, since
   the probes are directly touching). This confirms the meter and its
   battery are working. If you don't hear a beep here, replace the
   meter's battery before continuing.
3. To test whether two specific points in your build are connected, touch
   one probe to each point (order doesn't matter — continuity has no
   "direction"). **Beep = connected. Silence = not connected.**

### Voltage testing — step by step

Done with the circuit **powered on** (USB plugged in).

1. Set the dial to DC Voltage, appropriate range (20V range is fine for a
   3.3V circuit; auto-ranging meters just need "V DC" selected).
2. Touch the **black** probe to a GND point, and the **red** probe to the
   point you want to measure — e.g. the `3V3` pad, or the amp's `VIN` pin.
3. Read the number on the screen. If you get a negative number, it just
   means you have the probes reversed relative to how the meter defines
   positive — swap them, or just note the number's absolute value; it
   won't harm anything to have them "backwards" for a voltage reading.

---

## The staged testing procedure

Do these in order. Do not skip ahead to a later stage until the current
one passes.

---

### Stage 0 — Understand the system (done)

You've now read Parts 0–3 above. Before continuing, you should be able to
answer, in your own words: what does the board do, what does the amp do,
what does the touch pad do, and what does GND mean. If any of those still
feel shaky, re-read the relevant section above before continuing — the
rest of this guide assumes it.

---

### Stage 1 — Power-OFF visual inspection

**What we're doing:** looking at the physical build with your eyes (and a
magnifier/phone camera if needed), with zero power applied, to catch
obvious problems before they can cause any electrical damage.

**Why:** this catches the highest-value, lowest-effort class of problems —
loose connections, a wire on the wrong pad, a solder joint that's clearly
"cold" (dull and lumpy rather than shiny) — before you risk anything by
applying power. Skipping this and going straight to power-on means you
find these same problems the hard way, potentially after damage is done.

**Exact steps:**

1. Confirm the USB cable is fully unplugged from the board. Set it aside.
2. Open both pods (front and rear) so you can see the internals. If
   they're glued shut, stop and check with your teammate before forcing
   anything open.
3. Using the wiring table in Part 2, visually trace each of the six wires
   from its labeled pad on the board to its destination. For each one,
   confirm:
   - It's actually touching the pad it should be soldered/connected to
     (not just resting nearby).
   - The wire isn't touching any *other* pad or exposed metal it
     shouldn't be (this is what a short circuit looks like physically —
     two bits of bare metal touching that shouldn't be).
   - If soldered: the joint looks like a small **shiny, smooth** dome. A
     **dull, grey, or lumpy** joint may not be making a proper connection.
   - Gently (not forcefully) tug each wire. It should not move or pull
     free.
4. Check the camera ribbon is fully seated in its connector, with the
   small black latch pressed flat/closed (not sticking up).
5. Look specifically along the row of solder joints *from the side*, at
   table height, rather than from above. A bridge (blob of solder
   accidentally joining two adjacent pads) is often invisible from above
   but obvious from the side.

**Expected result:** every wire goes where the table says, joints look
shiny and solid, nothing wiggles, no two pads are touching each other.

**What a pass tells you:** the wiring is *probably* correct — but "looks
right" isn't proof of an actual electrical connection (a joint can look
fine and still not conduct — "dry joint"), which is exactly why Stage 2
exists.

**If you find a problem:** don't try to fix soldering yourself unless you
already know how — flag it to your teammate. Do not proceed to Stage 2
with a wire touching a pad it shouldn't be near, since that's the specific
short-circuit condition Stage 2's checks are designed to catch, and it's
safer to already know about it.

**Safety check before moving on:** USB still unplugged? Good, continue.

---

### Stage 2 — Continuity checks (multimeter, power OFF)

**What we're doing:** using the multimeter's continuity mode (see Part 3)
to electrically *prove* two things: (a) there is no short circuit between
power and ground, and (b) every intended connection actually conducts.

**Why:** this is the single most important safety gate in this whole
process. A short between `3V3` and `GND` can destroy the board the instant
you apply power — with no warning, no smell, sometimes no visible sign at
all until it simply doesn't turn on again. This check costs about two
minutes and catches it before any power is involved.

**Confirm before starting:** USB unplugged. Multimeter set to continuity
mode (`)))`), probes touched together to confirm a beep (see Part 3).

**Step 2a — the four checks that MUST be silent (no beep):**

| Touch probe 1 to | Touch probe 2 to | Expected |
|---|---|---|
| `3V3` pad | `GND` pad | **Silence.** A beep here means a short — stop, do not power on. |
| `D8` pad | `D9` pad | Silence |
| `D9` pad | `D10` pad | Silence |
| `D10` pad | `3V3` pad | Silence |

Each of these pairs is a *neighbouring* pad on the board — the classic way
an accidental solder bridge forms. If any of these beep, there's a bridge
of solder joining two pads that shouldn't be joined. This must be found
and fixed before you go any further — see the troubleshooting tree at the
end of this guide.

**Step 2b — the checks that SHOULD beep (this proves the wire actually works):**

For each of the six wires in the Part 2 table, touch one probe to the pad
on the board, and the other probe to the *far end* of that same wire
(e.g., at the amp's corresponding pin). This proves current can actually
flow along that specific wire — a joint can look perfect and still not
conduct (a "dry" or "cold" joint).

| Board pad | Far end to touch | Expected |
|---|---|---|
| `3V3` | Amp `VIN` | **Beep** |
| `GND` | Amp `GND` | **Beep** |
| `D8` | Amp `BCLK`/`SCK` | **Beep** |
| `D9` | Amp `LRC`/`WS` | **Beep** |
| `D10` | Amp `DIN` | **Beep** |
| `D2` | Touch disc | **Beep** |

**What a full pass means:** no shorts, and every intended wire actually
conducts end to end. This is the point where it becomes reasonably safe to
apply power for the first time.

**If step 2a finds a beep (a short):** **Do not proceed to power-on.**
Go to the "Bridge found" branch of the troubleshooting tree at the end of
this document.

**If step 2b finds silence where you expected a beep:** that specific wire
isn't making a connection somewhere along its length — a cold joint, a
loose push-on connector, or a broken wire. Note which one, and fix that
specific joint (or have your teammate do it) before continuing. Don't
apply power with a known-broken signal wire; it won't cause damage, but
you'll waste time debugging what looks like a software problem later when
it's actually this.

**Safety check before moving on:** all four "must be silent" checks passed
silent, and all six "should beep" checks beeped? Then, and only then,
continue to Stage 3.

---

### Stage 3 — Power supply verification (multimeter, power ON)

**What we're doing:** plugging in USB for the first time, and immediately
using the multimeter in voltage mode to confirm the board is actually
producing the 3.3V it's supposed to, before trusting it to run anything.

**Why:** Stage 2 proved the wiring is safe (no shorts). This stage proves
the power itself is actually correct — it's possible for a board to power
up but for something to be subtly wrong (a bad USB cable delivering
insufficient power, for example) that voltage measurement catches and a
visual check wouldn't.

**Exact steps:**

1. Set the multimeter to DC Voltage mode.
2. Plug the USB cable into the board and into your laptop (or a USB power
   brick).
3. **Within the first 5 seconds**, gently touch the board and the amp
   module with a fingertip (a quick dab, not holding it there). Both
   should feel cool or barely warm. **If anything feels distinctly warm
   or hot, unplug the USB cable immediately** and return to Stage 2 — this
   means there's a short that Stage 2 didn't catch (possibly something
   that only shorts once power is flowing, such as a wire that's *just*
   touching another pad under slight pressure).
4. If nothing is warm, look for a small LED on the board lighting up —
   this is a basic "it's receiving power" indicator.
5. Now measure: black probe on `GND`, red probe on `3V3`. Expected
   reading: **approximately 3.3V** (anywhere roughly 3.0–3.4V is normal).
6. Measure black probe on `GND`, red probe on amp `VIN`. Expected: also
   approximately 3.3V — since it's wired directly to the board's `3V3`
   pin, it should read the same.

**What a pass means:** the board is correctly powered, and that power is
correctly reaching the amp. You're now safe to move on to actually running
software.

**If you measure 0V or something far from 3.3V:** stop and go to the
troubleshooting tree ("No power reading" branch).

**If nothing lit up and the board seems completely dead:** try a different
USB cable first — a very common failure mode is a "charge-only" cable that
supplies power but has no data wires, or in rare cases a cable that
carries neither properly. Confirmed by trying a cable you know works with
another device.

---

### Stage 4 — Software/firmware setup (from scratch)

**What software/firmware is, again, in context:** your board doesn't do
anything on its own — it needs a program loaded onto it. Right now (fresh
from soldering) it very likely has no program on it at all, or an
unrelated factory-test program. You're going to install a program on your
laptop that can *build* the firmware code from the repo into a form the
board understands, and *send* it over the USB cable onto the board's
internal memory. This process is called **flashing** or **uploading**.

**Tool you need: PlatformIO** (a free extension for a program called VS
Code). VS Code is a text editor; PlatformIO is what teaches it how to talk
to microcontroller boards like yours.

**Setup steps:**

1. Download and install VS Code from `code.visualstudio.com`.
2. Open VS Code. Click the Extensions icon in the left sidebar (looks like
   four small squares, one pulled away from the rest) — or press
   `Ctrl+Shift+X` (`Cmd+Shift+X` on Mac).
3. Search for `PlatformIO IDE`, click Install. This takes several minutes
   the first time — let it finish uninterrupted.
4. Restart VS Code when prompted. You should now see a small toolbar
   along the very bottom edge of the window (a checkmark, a right-arrow,
   and a plug icon) — this is the PlatformIO build toolbar, and you'll use
   these three icons repeatedly.
5. In VS Code: `File → Open Folder`, and select the **`firmware`** folder
   specifically (not the parent repo folder — PlatformIO looks for a file
   called `platformio.ini`, which lives directly inside `firmware/`).
6. Wait for the bottom bar to finish "configuring" (first time only — it's
   downloading additional tools for this specific board). Several minutes.

**How your laptop identifies the board (the USB/serial port):**

Every device plugged into USB gets assigned an identifier by your
computer — on a Mac this looks like `/dev/cu.usbmodem1101`, on Windows
it's something like `COM5`. You don't need to memorize this, but it's
useful to understand what you're looking at when you see it. To check:

- Click the PlatformIO (alien head) icon in the left sidebar → "Devices"
  under PIO Home. You should see one entry appear/disappear when you
  plug/unplug the board — that's how you confirm you're looking at the
  right one, if more than one device is listed.

**Copying the secrets file:** the firmware needs your WiFi name/password
and your laptop's network address, kept in a file that's deliberately kept
out of the shared repo (so passwords don't get committed to GitHub).

1. In VS Code's file panel, find `src/secrets.h.example` inside `firmware`.
2. Copy it, paste it, and rename the copy to exactly `secrets.h` (same
   folder).
3. Open `secrets.h` and fill in your WiFi network name and password. You
   can leave the server address blank for now — it's not needed for the
   hardware self-test in the next stage.
4. **Important:** the ESP32S3 board only supports **2.4GHz WiFi**, not
   5GHz. If your home network is 5GHz-only, this will silently never
   connect — check your router settings if this comes up later.

---

### Stage 5 — Power-on test using the dedicated diagnostic program

This is the heart of the whole guide. Your teammate's repo already
contains a purpose-built diagnostic program (`selftest.cpp`) whose entire
job is exactly what you're trying to do: check each piece of hardware,
one at a time, in a safe order, and report PASS/FAIL in plain English.
Use this instead of the "real" firmware for all testing — the real
firmware (`main.cpp`) assumes everything already works, which makes it a
much worse tool for finding out whether that's true.

**What "uploading" and "the serial monitor" mean, concretely:**

- **Uploading** = clicking the right-arrow icon in the bottom toolbar.
  PlatformIO converts the code into a form the chip understands and sends
  it over USB. You'll see a wall of text scroll by, ending in `SUCCESS` (or
  a red error, which is not success).
- **Serial Monitor** = a window that shows text messages the board sends
  back to your laptop while it's running. This is how the diagnostic
  program tells you what it found. Open it by clicking the plug icon 🔌
  in the bottom toolbar.

**Exact steps:**

1. At the very bottom of VS Code, click where it shows the current
   "environment" name (near the alien-head icon). Select **`selftest`**
   from the menu (as opposed to the default environment, which builds the
   real firmware). This matters — building the wrong one either won't run
   the diagnostics, or will collide, since both programs can't run at
   once.
2. Click the checkmark icon (Build) first, just to confirm it compiles
   without errors.
3. Click the right-arrow icon (Upload). Wait for `SUCCESS`.
   - If it says it can't find the port: hold the **BOOT** button on the
     board, tap **RESET**, release BOOT, then click Upload again. (These
     are two small physical buttons on the board itself.)
4. Click the plug icon (Serial Monitor).
5. Press the **RESET** button on the board (the test runs automatically
   on boot, so you may need to reset to see it from the very start).
6. Read the output. It will run through, in this order, and this order is
   deliberate — **the first failure in the list is the one to actually
   fix; everything below it may just be a knock-on symptom, not a
   separate problem**:

   **a. PSRAM check.** PSRAM is a chunk of extra memory the camera needs
   to store a photo temporarily. This must PASS before the camera can
   possibly work — if PSRAM fails, that's a board configuration setting,
   not a wiring problem, and it needs fixing before camera testing means
   anything.

   **b. Camera check.** Confirms the camera initializes and can actually
   capture a frame of a sensible size (a failure here after PSRAM passed
   usually points at the ribbon cable connector, per Stage 1).

   **c. Touch pad calibration (interactive).** The program prints a
   baseline reading with nothing touching the pad, then asks you to hold
   your finger on the coin/screw-head for about 8 seconds while it streams
   live numbers. **Do this — don't skip it.** It will tell you the exact
   two settings your build needs (`TOUCH_ACTIVE_HIGH` and
   `TOUCH_THRESHOLD`) based on your *actual* physical pad, glue, and wire
   — these vary from build to build and cannot be reliably guessed or
   copied from someone else's numbers.

   **d. Audio test.** Plays a plain, clean 440Hz tone (a musical note,
   "A") directly through the amp and speaker — no file decoding involved,
   so if you hear it, the entire audio wiring chain (all three signal
   wires plus power) is proven correct, independent of anything
   software-related later.

   **e. WiFi test.** Confirms the board can join your network using the
   credentials from `secrets.h`.

   **f. Server reachability test.** Only relevant once you're running the
   `server/` program on your laptop (see Stage 6b) — it will report
   "skipped" if WiFi isn't connected, which is expected and fine at this
   point.

7. At the end, it prints a summary count and, if anything failed, a
   numbered list of what to fix, in the correct order.

**What to do with each individual result — decision tree:**

- **PSRAM: FAIL** → This is a board settings issue (`OPI PSRAM` needs to
  be enabled in the build configuration), not a soldering problem. This
  should already be set correctly in the repo's `platformio.ini` — if it
  still fails, this is a "flag to your teammate / check the repo file
  itself" situation rather than something to re-solder.
- **Camera: FAIL, PSRAM passed** → Power off, re-check the camera ribbon
  cable is fully seated with the latch closed flat (Stage 1, step 4).
  Re-test.
- **Touch: readings barely move when you touch it** → the white wire
  likely isn't making contact with the metal disc. Check that specific
  solder joint (Stage 1 and Stage 2 already tested D2-to-disc continuity
  — if that passed but this still fails, the disc's *surface* itself may
  need to be scuffed with sandpaper, since solder and capacitive sensing
  both need a clean electrical contact to the actual conductive surface a
  finger will touch).
- **Audio: I2S output failed to start** → power off, re-check `D8`, `D9`,
  `D10` connections from Stage 2 (this shouldn't happen if those all
  passed continuity, but re-verify nothing shifted).
- **Audio: "Tone played" passed but you heard nothing** →
  - Check whether the amp's `SD`/`SHUTDOWN` pin has accidentally been
    connected to GND (should be completely unconnected — see Part 2).
  - Measure amp `VIN` to `GND` with the meter (Stage 3 method) — expect
    ~3.3V. If you read 0V here even though the board's own `3V3` read
    correctly in Stage 3, the red wire between them has failed since
    Stage 2 (re-check that specific joint).
  - Confirm the speaker's two wires are actually connected to the amp's
    output terminals.
- **Audio: loud static/buzzing instead of a clean tone** → `BCLK` and
  `LRC` (yellow and green wires) are very likely swapped. Power off,
  swap them, re-test.
- **WiFi: FAIL** → double-check the WiFi name/password in `secrets.h`,
  and confirm the network is 2.4GHz (see Stage 4).

**Safety note for this whole stage:** every time you make a physical
change to the wiring based on a failure above, **unplug USB first**, make
the change, then re-run Stage 2's relevant continuity check before
re-powering — don't just re-plug in and hope. This keeps you from ever
powering a circuit you've just changed without having re-verified it.

---

### Stage 6 — Test communication with the software side

**6a. What's already been tested:** WiFi and (if applicable) server
reachability were already part of the `selftest` run in Stage 5. If those
passed, the board can talk to your laptop's network successfully.

**6b. Testing the actual AI server (optional at this stage, but useful
context):** the `server/` folder contains a separate program that runs on
your laptop (not the board) and does the "AI reads the label" part. You
can prove this half of the project works completely independently of any
hardware, using a tool called `curl` (a command that sends a file to a
web address from a terminal window):

```
cd server
pip install -r requirements.txt
uvicorn main:app --host 0.0.0.0 --port 8000
```

Then, in a second terminal window, with a photo of a label saved as
`box.jpg` in that same folder:

```
curl -X POST http://localhost:8000/read_label -F "image=@box.jpg"
```

If this returns a description of the label, the entire non-hardware half
of the project is proven to work, and any remaining problems are
definitely hardware/wiring, not the AI logic. This is a genuinely useful
diagnostic even before your hardware is fully working, because it narrows
down where a problem could possibly be.

---

### Stage 7 — Full system test

Only attempt this once every check in Stage 5 has passed.

1. Switch the PlatformIO environment (bottom toolbar) from `selftest`
   back to the real one (`seeed_xiao_esp32s3`).
2. Fill in the server address (`SERVER_HOST`) in `secrets.h` — find your
   laptop's local network address by running `ipconfig getifaddr en0`
   (Mac), `ipconfig` and reading the IPv4 address (Windows), or
   `hostname -I` (Linux).
3. Make sure the `server/` program (Stage 6b) is running in a terminal.
4. Upload the real firmware, open the Serial Monitor, and press RESET.
   Expect to see `WiFi connected` then `Glasses ready`.
5. Touch the pad (or press the button). Watch for: the board printing
   that it triggered, the server's terminal logging a request arriving,
   and — the actual product working — the speaker reading back whatever
   the camera is pointed at.
6. Repeat this ten times with different objects. Count failures. Anything
   less than ten clean successes is a reliability issue to chase down
   before demo night, not a hardware pass/fail question at this point.

---

## Troubleshooting decision tree (summary)

```
Multimeter beeps on 3V3–GND (Stage 2)?
  → STOP. Do not power on.
  → Look along the solder joints from the side (Stage 1, step 5) for a
    bridge of solder connecting two pads.
  → Clean the iron tip, drag it firmly across the bridge, away off the
    edge of the board. Re-test continuity. Repeat until silent.

A wire fails its "should beep" continuity check (Stage 2)?
  → That joint isn't conducting even though it may look fine.
  → Re-heat that specific joint until it flows, hold still 3 seconds while
    it cools, re-test.

Board/amp feels warm within 5 seconds of power-on (Stage 3)?
  → Unplug immediately.
  → Return to Stage 2 continuity checks — something is shorting only
    under load/pressure that a static check might have missed.

3V3 pad reads far from 3.3V, or 0V (Stage 3)?
  → Try a different USB cable (many are charge-only, no data).
  → If still 0V, this points to a board power-regulation fault — flag to
    your teammate rather than continuing to test downstream components.

selftest: PSRAM fails?
  → Configuration issue (OPI PSRAM setting), not a wiring problem.
  → Confirm platformio.ini hasn't been edited; otherwise flag it upstream.

selftest: Camera fails, PSRAM passed?
  → Power off. Re-seat the camera ribbon, confirm the latch is fully
    closed flat. Re-test.

selftest: Touch barely moves between untouched/touched readings?
  → Confirm D2–disc continuity (Stage 2) still passes.
  → If it does, the disc's surface likely needs scuffing (sandpaper) so
    solder — and a finger — make proper contact.

selftest: "Tone played" = PASS but you hear nothing?
  → Check amp SD/SHUTDOWN pin is completely unconnected.
  → Meter amp VIN–GND: expect ~3.3V. If 0V, re-check the red wire joint.
  → Confirm speaker leads are actually on the amp's output terminals.

selftest: static/buzzing instead of a clean tone?
  → BCLK and LRC (yellow/green) are almost certainly swapped.
  → Power off, swap them, re-test.

selftest: WiFi fails?
  → Check secrets.h credentials.
  → Confirm the network is 2.4GHz, not 5GHz-only.
```

---

## Final testing checklist

Print this or keep it open next to you. Do not check off a box until
you've actually done that step and gotten the expected result.

**Before any power:**
- [ ] Photographed both pods, lids off, good lighting
- [ ] Every wire in Part 2's table visually traced and matches (or
      discrepancies noted and understood)
- [ ] No two pads touching that shouldn't be
- [ ] All solder joints look shiny/smooth, not dull/lumpy
- [ ] Every wire gently tugged, none move
- [ ] Camera ribbon fully seated, latch closed flat

**Continuity checks (multimeter, power still OFF):**
- [ ] `3V3`–`GND`: silent
- [ ] `D8`–`D9`: silent
- [ ] `D9`–`D10`: silent
- [ ] `D10`–`3V3`: silent
- [ ] `3V3` → amp `VIN`: beeps
- [ ] `GND` → amp `GND`: beeps
- [ ] `D8` → amp `BCLK`: beeps
- [ ] `D9` → amp `LRC`: beeps
- [ ] `D10` → amp `DIN`: beeps
- [ ] `D2` → touch disc: beeps

**First power-on:**
- [ ] USB plugged in, board/amp checked for warmth in first 5 seconds — cool
- [ ] Board LED lit
- [ ] `3V3` measures ~3.3V
- [ ] Amp `VIN` measures ~3.3V

**Software setup:**
- [ ] VS Code + PlatformIO installed
- [ ] `firmware` folder opened directly (not the repo root)
- [ ] `secrets.h` created from the example, WiFi filled in

**selftest diagnostic run:**
- [ ] PSRAM: PASS
- [ ] Camera init: PASS
- [ ] Camera capture: PASS (reasonable byte size, not near-zero)
- [ ] Touch calibration run, `TOUCH_THRESHOLD`/`TOUCH_ACTIVE_HIGH` noted
      and written into `pins.h`
- [ ] Audio: I2S output started
- [ ] Audio: tone actually heard through the speaker
- [ ] WiFi: connected

**Full system:**
- [ ] Real firmware flashed, `SERVER_HOST` set
- [ ] Server running on laptop (`uvicorn ...`)
- [ ] Touch → capture → server log → spoken reply, confirmed once
- [ ] Repeated 10x, failure count noted

You're done with hardware/wiring verification once every box above is
checked. Anything that fails past this point is very likely a software,
network, or AI-prompt issue rather than a wiring one — worth knowing,
since it changes who on the team should look at it next.

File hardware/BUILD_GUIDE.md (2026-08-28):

# Vocalens — build guide

Step by step, from printed parts to a working device. Two pods, kit parts
only, zero purchases — the committed build for this event.

## What you need

**From the Freenove kit** (check the parts poster — you have all of these):

| Part | Used for |
|---|---|
| Camera module (stays attached to its FPC ribbon) | Front pod — the eye of the device |
| Speaker | Rear pod — speaks the answer |
| Audio Converter & Amplifier | Rear pod — drives the speaker over I2S |
| Jumper wires (M-M, F-F, F-M) | Front-to-rear connection (5 wires) + all local wiring |
| 2×AA battery holder **or** 9V battery cable | Untethered power (optional — USB works too) |

**Your own:** XIAO ESP32S3 Sense, a pair of glasses you don't mind clipping
onto.

**Nothing else.** No purchases for this build. A hidden cable, a
camera-only front pod, and bone conduction are documented in
`hardware/README.md` as pitch material for "what we'd build next" — not
sourced, not needed here.

---

## Step 1 — Measure, before you print anything

Open `cad/vocalens_pod.scad` and update these to your real parts. Callipers
if you have them; a ruler is good enough to start.

| Parameter | Measure |
|---|---|
| `TEMPLE_THICKNESS`, `TEMPLE_WIDTH` | The temple arm of your glasses |
| `CAM_LEN/WID/HGT` | The camera module, still attached to its ribbon |
| `XIAO_LEN/WID/HGT` | The XIAO board (camera stays attached — its height is added automatically, don't double-count it) |
| `SPKR_DIA`, `SPKR_HGT` | The kit speaker |
| `AMP_LEN/WID/HGT` | The audio amplifier module |

## Step 2 — Print the fit test first

```
openscad -o fit_test.stl -D 'part="fit_test"' cad/vocalens_pod.scad
```

Or slice the supplied `cad/fit_test.stl` directly. ~3 minutes to print.

Snap it onto your glasses:

- **Won't go on / splays the arm** → increase `SNAP_GAP`
- **Slides around loosely** → decrease `SNAP_GAP`
- **Rattles in the channel** → your `TEMPLE_*` measurements are too big

Re-print until it grips. Do not skip this — it is the difference between one
wasted evening and four.

## Step 3 — Print both pods

Slice `cad/split_plate.stl` — front pod, rear pod, both lids, and a spare
fit test, 113 × 48mm total, comfortably inside the Snapmaker U1's 270mm bed.

Both pods are intentionally thin top-to-bottom (~10mm) and extend outward
from the head instead — see `hardware/README.md` for why that orientation
is what keeps this off the wearer's scalp instead of resting on top of it.

**Snapmaker U1 settings:**
- Layer height 0.16mm
- 4 perimeters (matches the 1.6mm `WALL`)
- Print as modelled, cavity-up — no supports needed in that orientation
- Both lids in the plate are pre-flipped rib-side-up so they sit flat with
  no supports
- **Print bases in TPU, lids in PETG** — the base is what flexes on every
  clip-on/off, TPU handles that fatigue far better than rigid filament and
  forgives small `SNAP_GAP` errors; the lid just needs to hold its shape.
  No CAD changes needed, just a material choice per part. TPU wants its own
  slicer profile (slower, less retraction) — test it on something small
  first if that's not already dialled in on the U1.
- Use PLA for `fit_test.stl` iterations only — fastest print, and you'll
  redo it a few times while tuning `SNAP_GAP`

## Step 4 — Wire it up

All connections are jumper wires. Nothing here needs soldering except
possibly the speaker leads.

**Front pod → rear pod (I2S, 5 wires, run along the temple arm):**

| Signal | XIAO pin (front pod) | Amp pin (rear pod) |
|---|---|---|
| BCLK / SCK | GPIO 7 (`PIN_I2S_BCLK`) | BCLK |
| LRC / WS | GPIO 8 (`PIN_I2S_LRC`) | LRC |
| DIN | GPIO 9 (`PIN_I2S_DIN`) | DIN |
| Power | 3V3 | VIN |
| Ground | GND | GND |

Use the longer jumper wires from the kit for this run — measure the temple
arm length first and pick wires with a bit of slack, not the shortest ones
you have.

**Speaker → amp (in the rear pod):** the two speaker output terminals.
Polarity doesn't matter for a single speaker.

**Touch pad (in the front pod):** run one jumper wire from **GPIO 3**
(`PIN_TOUCH_PAD`) to a small piece of metal — a coin, a screw head, a scrap
of foil — glued into the recess in the front lid. ESP32 capacitive touch
needs no sensor component; the bare wire and a conductive surface are the
whole circuit.

**Power:** USB-C to a laptop or power bank, into the front pod, is simplest
and most reliable for a demo. If you want untethered, the 2×AA holder gives
~3V — wire it to the XIAO's BAT pads. The XIAO expects a LiPo on those pads,
so check voltage before connecting anything.

## Step 5 — Assemble

**Front pod:**
1. Seat the XIAO (camera attached) in the cavity, lens aligned with the
   front hole. A dab of hot glue holds it.
2. Glue the touch-pad metal into its recess in the lid, connect its wire.
3. Feed the 5 I2S wires out through the rear-face slot.
4. Route the USB cable out through the side slot.
5. Press the lid on.

**Rear pod:**
6. Feed the 5 I2S wires in through the front-face slot, connect to the amp.
7. Seat the amp and speaker side by side in the cavity, speaker under the
   grille holes in the lid.
8. Press the lid on.

**Both:**
9. Clip the front pod onto the temple arm near the hinge, camera forward.
10. Clip the rear pod behind the ear.
11. Run the 5 wires along the top edge of the temple arm between them; a
    dot of removable adhesive at one or two points keeps them tidy and
    stops them snagging.

## Step 6 — Bring it up in this order

Do not try to make everything work at once. Each step below is testable on
its own, and each one you skip is a bug you'll be hunting at 2am.

1. **Camera only, on the bench, pods not yet wired to each other.** Flash,
   hit `/read_label` with the touch pad, confirm the server receives a
   frame. No audio, no mic.
2. **Audio out, still on the bench** with short wires between the two pods
   before committing to the full temple-length run. Confirm the server's
   spoken reply plays through the speaker.
3. **Now extend to the full temple-length wires** and clip both pods on.
   Re-test — a longer run occasionally needs a small pull-up/pull-down
   tweak if signals get noisy, though I2S at this length usually doesn't.
4. **Mic in.** Record a question, confirm the server transcribes it.
5. **Wake word last.** It's the highest-risk piece (see
   `firmware/src/wake_word.h`) and the touch pad already gets you a working
   demo without it.

## Known rough edges — say these plainly in the pitch

- **Jumper wires run exposed** along the temple arm between the pods. Not
  hidden, not strain-relieved. Direct, honest cost of a two-pod split with
  zero external sourcing — a hidden cable or sheath is named as future work
  in `hardware/README.md`.
- Outer corners are lightly rounded (1mm) but the overall shape is still a
  utilitarian bar, not a finished consumer product. Further shaping is a
  cheap next iteration and worth doing before demo night.
- No strain relief where any cable exits either pod.

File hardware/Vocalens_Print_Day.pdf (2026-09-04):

# VocaLens — print day

Two jobs, different materials. Start the PETG first — it is the long one, and the TPU can run after it or on a second machine.

JOB 1 · PETG · the two pods | ~3 h
File | FINAL_petg_plate_HEADERS.stl — your XIAO has 2×7 headers soldered on, so this is the one. This build assumes the amplifier is wired WITHOUT sockets — wires soldered straight to its pads. That is what makes the rear pod 10mm slimmer. If your amp still has jumper sockets pushed onto pins, this pod will not close over it: print FINAL_petg_plate_AMPSOCKETS.stl instead.
What is on it | 4 parts: front pod base, front pod lid, rear pod base, rear pod lid
Material | PETG (PLA is acceptable if PETG is not free — it is stiffer and more brittle, but it fits)
Layer height | 0.2 mm
Infill | 25 %
Perimeters / walls | 3
Supports | OFF
Brim | ON — the pods are tall and narrow and can be knocked over
Plate size | 105 × 108 × 27 mm — fits any printer at the venue

Why supports off: the plate is already arranged so nothing overhangs. The pods sit cavity-up and the lids sit flat face down. If your slicer warns about overhangs, something imported wrong — do not switch supports on to silence it.

JOB 2 · TPU · the four rings | ~40 min
File | Not measured your glasses arm yet? Print FINAL_tpu_rings_LADDER.stl first — four graduated sizes, ~40 min, smallest on the left. Fit each in turn and keep the smallest that goes on. Once you know the size: FINAL_tpu_rings.stl for four of it.
What is on it | 4 copies of one small ring — 2 per pod, plus spares. All ring sizes carry an identical dovetail rail, so whichever size fits your frame still mates with the pods you already printed.
Material | TPU / flexible filament. This one cannot be substituted
Layer height | 0.2 mm
Infill | 20 %
Perimeters / walls | 2 — not 3. The wall is only 1.2 mm; more perimeters make it too stiff to stretch
Print speed | 20–25 mm/s. TPU jams if pushed fast
Retraction | Near zero (0.5 mm or less)
Supports | OFF
Plate size | 68 × 10 × 12 mm (ladder 68 × 14 × 13 mm)

If the venue has no TPU, print the rings anyway in the softest filament available and expect them to grip poorly, then say so — but ask around first. The rings are the only part that has to flex, and a rigid ring will crack rather than stretch onto the arm.

### WHEN THEY COME OFF THE BED — check in this order

1. Slide a ring onto your glasses temple arm. It should need a firm push and then stay put on its own.

If it is loose, go down one step on the ladder — or reduce RING_IN_VERT / RING_IN_OUT in vocalens_ring.scad by 0.5 mm and reprint one ring (10 minutes). If it will not go on at all, go UP a step. Smaller is the safer direction but it has a floor: TPU grips best at 20-30 % stretch, and past that it either refuses to fit or takes a permanent set and grips worse. Aim for roughly 75-85 % of the arm's measured section.

2. Slide a pod base onto a ring's dovetail rail, along the arm. It should need real effort and should not rattle or lift off sideways.

If it will not go on at all, lower DT_SQUISH from 0.45 to 0.35. If it rattles, raise it to 0.55.

3. Drop a lid onto its base. The rib should sit inside the cavity and the lid should sit flush.
4. Check the front lid has two openings: a round hole near one end for the camera, and an 18 × 20 mm oval recess near the other for the touch pad, with a small hole through the middle of the oval.

The small hole is for the touch wire. Solder the wire to the back of the pad before gluing the pad into the recess
— afterwards you cannot reach it, and nothing conductive should be exposed where a finger touches.
5. Check the rear lid has a ring of small holes — that is the speaker grille.
6. Drop the amplifier into the rear pod before you glue anything.

This is the one clearance the slim design spends. If the amp still has sockets on it, it will not go in — and you want to find that out now, holding both parts, not at midnight with wires already run.

### TAKE WITH YOU

☐ Laptop with the STL files on it (or the GitHub repo open)
☐ USB stick or SD card — most venue printers will not take a network job
☐ The glasses you are mounting to — the ring fit test is the whole point and cannot be done later ☐ Your assembled XIAO + camera, to check it drops into the front pod cavity
☐ The speaker and amplifier, to check they drop into the rear pod cavity
☐ Superglue or double-sided tape for the touch pad

Print the TPU rings even if you are short on time. The pods are useless without them, and they are the fastest part on the list.

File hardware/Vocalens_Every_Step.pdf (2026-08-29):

# Every Single Step

42 steps. One action each. Nothing skipped.

How to use this. Do step 1. Read the green "you should see" line and check it actually happened. Only then do step 2. If the green line didn't happen, the red line tells you what to do. Never skip ahead — every step assumes the one before it worked.

Two safety things, once. The iron is 350°C and looks identical hot or cold — assume it is always hot, and put it back in its stand every single time you let go of it. Solder fumes are unpleasant: work somewhere with a window open, and don't lean directly over the joint.

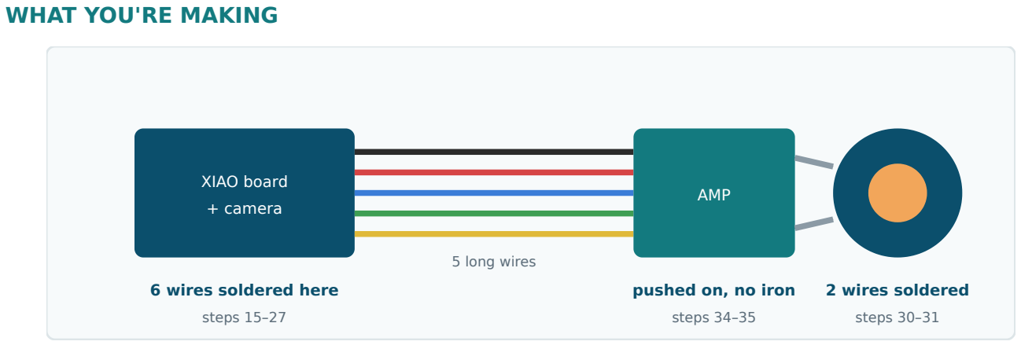
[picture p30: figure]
WHAT YOU'RE MAKING; XIAO board + camera; 6 wires soldered here; steps 15–27; 5 long wires; AMP; pushed on, no iron; steps 34–35; 2 wires soldered; steps 30–31

Total: 9 soldered joints. Six on the board, two on the speaker, one on a coin. Everything else is cutting, stripping, plugging in, and checking. Most of these 42 steps involve no iron at all.

V O C A L E N S · D O T H I S E X A C T LY

Every Single Step | Cover

## PART 1 — Set up your bench

1 Unplug the USB cable from the XIAO board.
If it isn't plugged in, good — leave it that way.
You should see: nothing connected to the board at all.
Why: soldering a powered board can destroy it.

2

Put the board on the table with the USB socket pointing away from you.
The silver USB socket is at one short end. Point that end away.
You should see: a row of 7 small silver pads down the left edge, and 7 down the right.

3

Tape the board down.
A loop of tape under it, or tape over each end. Any tape.
You should see: the board doesn't slide when you nudge it.
Why: one hand holds the iron, one holds the solder. You have no hand left for the board.

4

Find the writing next to the pads.
Tiny text: D0 D1 D2 D3 D4 D5 D6 on one edge, and 5V GND 3V3 D10 D9 D8 D7 on the other. Use your phone camera zoomed in if you can't read it.
You should see: you can point at the pad labelled 3V3 and the one labelled D8 .
If you can't find these: stop and message me a photo. Everything else depends on this.

5

Plug the soldering iron in and set it to 350°C.
No temperature dial? Just plug it in. It'll settle wherever it settles and that's usually fine. You should see: it takes 2–5 minutes to heat. Wait.

6 Wet the sponge in the iron's stand.
A splash of water. Damp, not soaking — squeeze the excess out. You should see: a damp sponge that doesn't drip.

7 Once hot, wipe the iron's tip on the wet sponge.
One quick drag. It will hiss and steam — that's correct.
You should see: the very tip goes shiny silver instead of dull black.

8

Touch solder to the tip until a bead forms, then wipe again.
This is called "tinning the tip". Melt a bit of solder onto it, wipe most off.
You should see: the tip stays bright silver and shiny.
If it stays black: the tip is oxidised. Repeat 7–8 twice more. A black tip will not transfer heat and nothing else will work.

No iron yet. Steps 1–8.

Part 1 — Set up | Steps 1–8

## PART 2 — Prepare the wires

9

Put your glasses on the table and measure along one arm.
From the hinge (where the arm meets the lens) to the point that sits behind your ear. Use a ruler. You should see: a number, roughly 10–14 cm. Write it down.

10

Add 2 cm to that number. This is your cut length.
So 12 cm measured → cut at 14 cm.
You should see: one number written down that you'll use five times.
Why: wires always need more slack than you think. Too long tucks away; too short is unfixable.

11

Cut FIVE wires to that length: one red, one black, one yellow, one green, one blue.
If your jumper wires have plastic plugs on the ends, cut those off — you need bare wire.
You should see: five wires of equal length in five different colours.
No blue or green? Any five distinct colours work. Just write down which colour you chose for which job and stick to it.

12

Cut ONE more wire, white, about 5 cm long.
Much shorter — this one never leaves the front pod.
You should see: six wires total. Five long, one short.

13

Strip 3 mm of plastic off BOTH ends of ALL SIX wires.
3 mm is about the width of a matchstick. Strippers if you have them; otherwise score gently with a knife and pull the plastic off.
You should see: 12 bare metal ends, each about 3 mm long.
If you cut through the metal: snip that end off and strip again. It's fine, you have slack.

14

Twist each bare end tightly between your fingers.
The metal is many thin strands. Roll them together so they form one solid point.
You should see: 12 neat twisted points, no stray strands sticking out sideways. Why: one loose strand touching the next pad is a short circuit.

You're a third of the way through and haven't touched the iron. That's normal. Preparation is most of the job; the soldering itself is fast.

Still no iron. Steps 9–14.

Part 2 — Wires | Steps 9–14

## PART 3 — Put solder on the six pads

The move, for all six. Touch the iron tip to the pad. Count "one, two". Now touch solder to the pad (not the iron). It melts and spreads. Take the solder away, then the iron. Total: about 3 seconds.

15

Put solder on the pad labelled GND .
Right-hand edge, second one down from the USB end.
You should see: a small shiny silver dome covering the pad.
If the solder balls up and rolls off: the pad wasn't hot enough. Hold the iron on it longer before adding solder.

16

Put solder on the pad labelled 3V3 .
Third one down, right-hand edge.
You should see: a second shiny dome. It must not touch the first one.

17

Put solder on the pad labelled D10 .
Fourth down, right-hand edge.
You should see: three separate domes in a row.

18

Put solder on the pad labelled D9 .
Fifth down, right-hand edge.
You should see: four separate domes.

19

Put solder on the pad labelled D8 .
Sixth down, right-hand edge.
You should see: five separate domes.

20

Put solder on the pad labelled D2 — on the OTHER edge.
Left-hand edge, third one down. This is the only one on that side.
You should see: six domes total. Five on the right, one on the left.

21

Lower your eye to table level and look ALONG the row of five.
Not down from above — from the side, like looking along a shelf.
You should see: five separate bumps with clear gaps between them.
If any two are joined: wipe the iron tip clean, then drag it firmly across the join and away off the edge of the board. The solder follows the tip. Look again from the side.

Iron time. Steps 15–20.

Part 3 — Tin the pads | Steps 15–21

## PART 4 — Attach the wires

22

Put solder on ONE bare end of each of the six wires.
Hold the iron under the twisted end, count two, touch solder to the wire. It soaks in. Do all six, then continue.
You should see: six wire ends gone stiff and silver instead of coppery and floppy.
If the plastic shrinks back: you held it too long. Still fine as long as bare metal isn't touching bare metal.

The joining move, for all six. Hold the silvered wire end flat against the silvered pad. Touch the iron on top of both for one second — the two blobs merge into one. Lift the iron. Now do not move the wire for three seconds.

23

Solder the BLACK wire to GND .
You should see: one shiny joint. Tug the wire gently — it doesn't move.
If it looks dull, grey or crusty: you moved it while cooling. Just re-heat until it goes shiny, then hold still. Don't add more solder.

24

Solder the RED wire to 3V3 .
You should see: two joints, not touching each other.

25

Solder the BLUE wire to D10 .
You should see: three joints.

26

Solder the GREEN wire to D9 .
You should see: four joints.

27

Solder the YELLOW wire to D8 .
You should see: five joints, five wires leaving the right edge together.

28

Solder the WHITE wire to D2 on the left edge.
You should see: six joints. That's every joint on the board done.

29

Tug each of the six wires gently, then look along the edge again.
A firm pull, not a yank.
You should see: nothing moves, and no two joints are touching.
If a wire comes off: that joint was cold. Re-tin the pad and the wire end, and redo it.

The six real joints. Steps 22–29.

Part 4 — Attach the wires | Steps 22–29

## PART 5 — Speaker, touch pad, amplifier

30

Solder a short wire to one of the speaker's two metal tabs.
Any spare wire, about 4 cm. Same move: tin the tab, tin the wire, melt together. You should see: one wire attached to the speaker.
Speaker already has wires? Skip steps 30 and 31 entirely.

31

Solder a second short wire to the speaker's other tab.
It does not matter which wire goes to which tab. A single speaker has no correct way round. You should see: two wires attached to the speaker.

32

Rub sandpaper or a file over one face of your coin.
Any coin, or a wide screw head. Scratch it until it looks dull and scuffed, not shiny.
You should see: a dull, scratched patch about the size of a pea.
Why: solder will not stick to a shiny coin. This step is the whole reason the touch pad works.

33

Solder the WHITE wire's free end to the scuffed patch.
A coin is a big lump of metal, so it takes longer to heat — 5–10 seconds, not 2. Be patient.
You should see: the wire stuck firmly to the coin. That's all 9 joints done.
If solder won't stick: not scuffed enough, or not hot enough. Scuff harder, hold the iron longer.

34

Push the five long wires onto the amplifier's pins.
No soldering if your amp has pins sticking out — use jumper wires with plastic sockets, or just twist the bare wire tightly round each pin for now.
Red→ VIN · Black→ GND · Yellow→ BCLK · Green→ LRC · Blue→ DIN
You should see: five wires connected, each to the pin with the matching name.
Different names on your board? BCLK = SCK = CLK · LRC = WS = LRCLK · DIN = DATA . Same signals.

35

Connect the speaker's two wires to the amp's two output pins.
Labelled OUT+ and OUT− , or just + and − . Either wire to either pin.
You should see: the speaker connected to the amp.
Leave GAIN , SD and SHUTDOWN empty. Connecting SD silences the amp completely.

Last three joints. Steps 30–35.

Part 5 — Speaker, disc, amp | Steps 30–35

## PART 6 — Check it, then power it

Everything is still unplugged. Steps 36–40 happen with no power anywhere.

36

Set your multimeter to the beep/continuity setting.
The dial position marked with a sound-wave symbol ")))" or a diode triangle. Touch the two probes together — it should beep.
You should see: it beeps when the probes touch, stops when you part them.
No multimeter? Skip to step 41, but understand you're taking a real risk of killing the board.

37

Touch one probe to 3V3 and the other to GND .
You should see: SILENCE. No beep.
If it beeps: STOP. Those two are joined by stray solder — a dead short. Find it (look along the edge), drag it off with a clean hot tip, and test again. Do not plug in until this is silent.

38

Touch one probe to D8 and the other to D9 .
You should see: silence.
If it beeps: those two joints are bridged. Same fix as step 37.

39

Test D9 – D10 , then D10 – 3V3 .
You should see: silence both times.

### 40 Now check each wire actually works: one probe on a pad, the other on

that same wire's far end.
Do all six. This proves the joint conducts, not just that it looks attached.
You should see: a beep every time. This is the one test where beeping is good.
If one doesn't beep: that joint looks fine but isn't connected. Re-heat it until the solder flows.

41

Plug the USB cable in.
You should see: a small light on the board come on.
If nothing happens: unplug. Try the cable on something else — many USB cables are charge-only and carry no data.

42 Within 5 seconds, touch the board and the amp with a fingertip.
Quick dab, don't hold your finger there.
You should see: both are cool or barely warm.
If anything is hot: UNPLUG IMMEDIATELY. You have a short. Go back to step 37 and test everything again.

Done — all 42 steps. The board is wired. Next: flash the firmware, start the server, and test the camera before the audio. Never both at once, or you won't know which one is broken.

Steps 36–42. Do not skip.

Part 6 — Check and power | Steps 36–42

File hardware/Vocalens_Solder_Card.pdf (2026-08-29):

# Solder Card

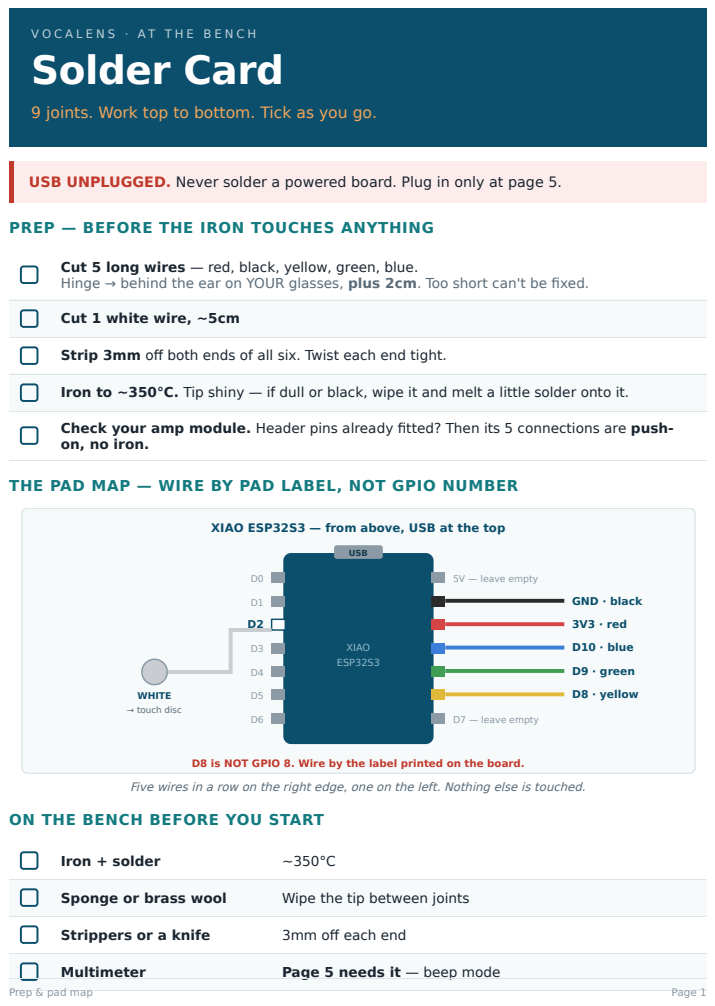
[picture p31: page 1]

9 joints. Work top to bottom. Tick as you go.

USB UNPLUGGED. Never solder a powered board. Plug in only at page 5.

PREP — BEFORE THE IRON TOUCHES ANYTHING

Cut 5 long wires — red, black, yellow, green, blue.
Hinge → behind the ear on YOUR glasses, plus 2cm. Too short can't be fixed.

Strip 3mm off both ends of all six. Twist each end tight.

Iron to ~350°C. Tip shiny — if dull or black, wipe it and melt a little solder onto it.

Check your amp module. Header pins already fitted? Then its 5 connections are push-
on, no iron.

THE PAD MAP — WIRE BY PAD LABEL, NOT GPIO NUMBER

XIAO ESP32S3 — from above, USB at the top

D8 is NOT GPIO 8. Wire by the label printed on the board.

Five wires in a row on the right edge, one on the left. Nothing else is touched.

ON THE BENCH BEFORE YOU START

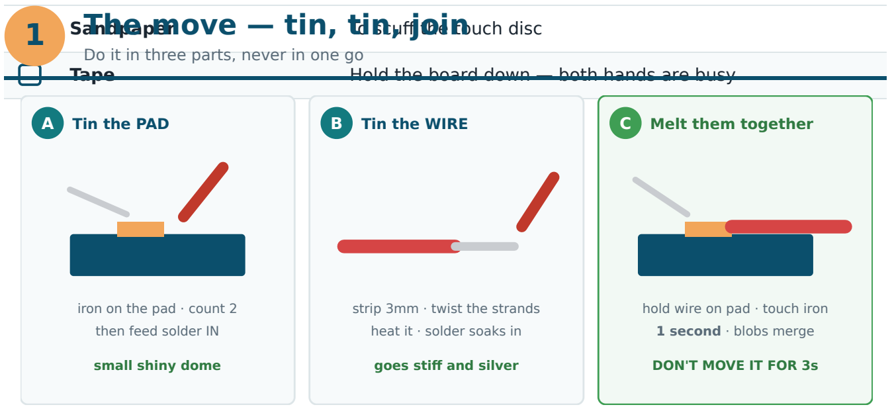
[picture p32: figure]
Sandpaper; To scuff the touch disc; The move — tin, tin, join; Do it in three parts, never in one go; A Tin the PAD; iron on the pad · count 2 then feed solder IN; small shiny dome; B Tin the WIRE; strip 3mm · twist the strands heat it · solder soaks in; goes stiff and silver; C Melt them together; hold wire on pad · touch iron 1 second · blobs merge; DON'T MOVE IT FOR 3s

Tape | Hold the board down — both hands are busy

Tinning both sides first turns each joint into a one-second touch instead of a three-handed wrestle.

Heat the PAD, not the solder.
That one sentence is most of learning to solder. Iron on the pad, count two, then bring the solder in so the pad melts it. Melting solder on the tip and dabbing it on makes a joint that looks fine and falls off later.

READING YOUR OWN JOINTS

What you see | What to do
Shiny, smooth, slightly dished | Good. Move on.
Dull, grey, lumpy | You moved it while cooling. Re-heat till it flows, hold still. Don't
| add solder.

Ball sat on top, not spread
out | Pad was cold. Re-heat the pad properly and it'll wet.
Blob bridging two pads | Fix now. Drag a clean hot tip across it, or use braid.
Technique | Page 2

2

## Joints 1–6 — the XIAO

Tin all six pads first, then all six wires, then join

Work top to bottom down the right edge. That way the iron never has to reach across a joint you've already made.

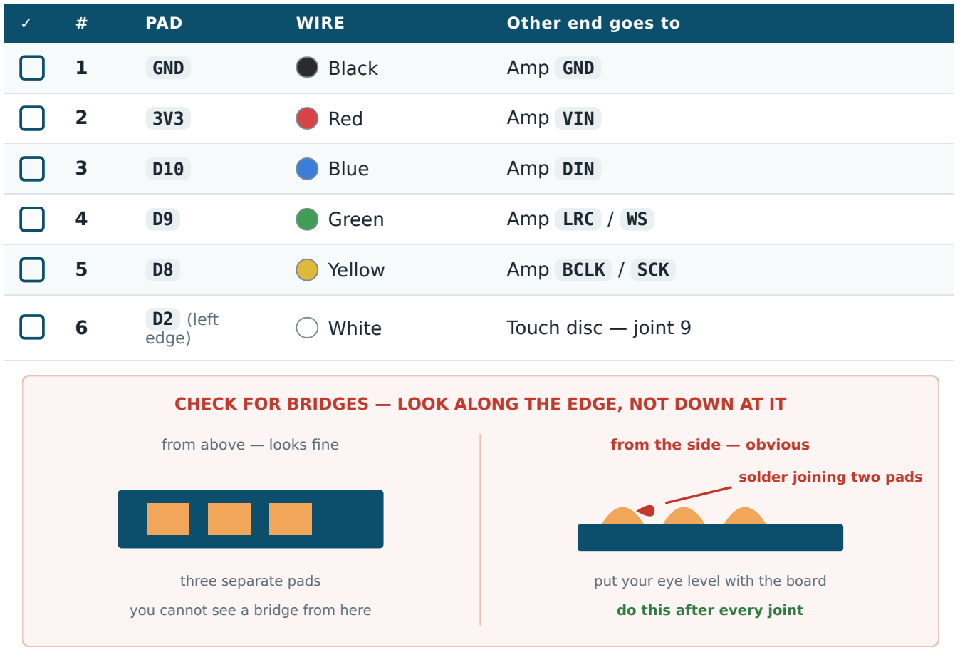
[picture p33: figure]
PAD; WIRE; Other end goes to; GND; Black; Amp GND; Red; Amp VIN; Blue; Amp DIN; Green; Amp LRC / WS; Yellow; Amp BCLK / SCK; D2 (left; edge); White; Touch disc — joint 9; from above — looks fine; three separate pads; you cannot see a bridge from here; from the side — obvious; solder joining two pads; put your eye level with the board; do this after every joint

CHECK FOR BRIDGES — LOOK ALONG THE EDGE, NOT DOWN AT IT

Tug every wire gently before you move on. A joint that pulls off on the bench will definitely pull off on someone's face.

Keep the blobs flat. The pod only has 10mm of height. If a joint stands proud, re-heat and let it settle rather than forcing the lid down on it.

Found a bridge? Wipe the tip clean, then drag it firmly across the bridge away from the pads. The solder follows the hot tip off the board. Re-check from the side. Don't add flux-less solder trying to "push" it apart — that makes it bigger.

Joints 1–6 | Page 3

3

## Joints 7–9, and the amp end

Nearly done

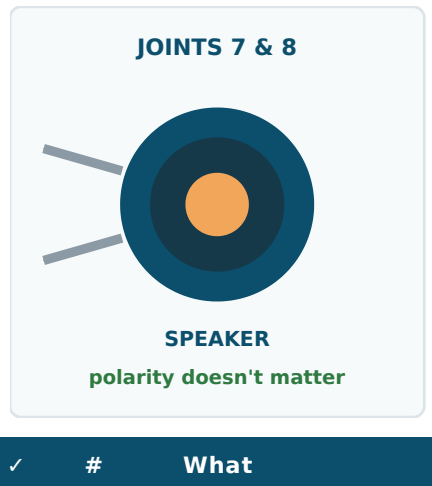
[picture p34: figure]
JOINTS 7 & 8; SPEAKER; polarity doesn't matter; What
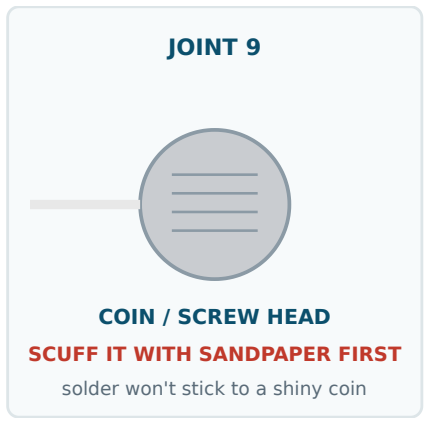
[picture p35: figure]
JOINT 9; COIN / SCREW HEAD; SCUFF IT WITH SANDPAPER FIRST; solder won't stick to a shiny coin

### 8 Short wire → speaker terminal two

### 9 White wire's free end → the scuffed metal disc

— | Speaker's two free ends → amp OUT+ and OUT−

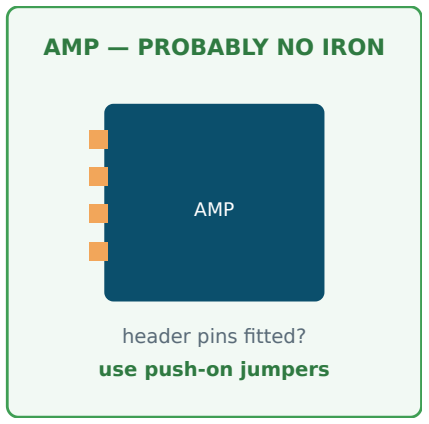
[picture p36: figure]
AMP — PROBABLY NO IRON; AMP; header pins fitted? use push-on jumpers

— | The five bundle wires → amp VIN GND BCLK LRC DIN

Leave GAIN , SD and SHUTDOWN unconnected. They have sensible defaults. SD usually means shutdown — grounding it silences the amp completely, and that is a very confusing

Amp label variants — all the same signals:
BCLK = SCK = CLK · LRC = WS = LRCLK · DIN = SD (data) = DATA
Joints 7–9 & amp | Page 4

4

## Check before you plug in

Two minutes. Do not skip it.

A bridge between 3V3 and GND is a dead short.
It can kill the board the instant you plug in. Find it with a meter, not with smoke.

MULTIMETER ON BEEP MODE — STILL UNPLUGGED

✓ | Touch these two | Expected
| 3V3 and GND | MUST NOT BEEP
D8 and D9 | must not beep
D9 and D10 | must not beep
D10 and 3V3 | must not beep

Each pad → its own far
wire end | must beep

Any beep in the first four rows = a solder bridge. Find it, drag a clean hot tip across it, re-test. Don't plug in until all four are silent.

THEN, AND ONLY THEN

IF SOMETHING'S WRONG

Symptom | Most likely cause
Board won't appear on laptop | Unplug what you soldered. Appears bare → you have a short.
Camera never starts | PSRAM, not wiring — already fixed in the config.

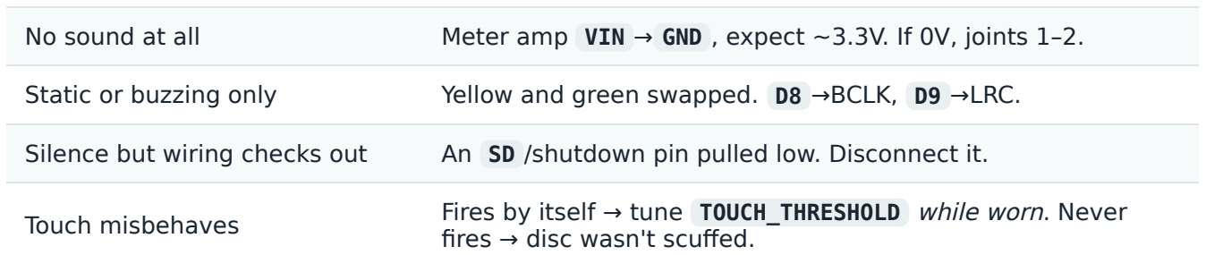
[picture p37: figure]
fires → disc wasn't scuffed.

No sound at all | Meter amp VIN → GND , expect ~3.3V. If 0V, joints 1–2.
Static or buzzing only | Yellow and green swapped. D8 →BCLK, D9 →LRC.
Silence but wiring checks out | An SD /shutdown pin pulled low. Disconnect it.
Touch misbehaves | Fires by itself → tune TOUCH_THRESHOLD while worn. Never

1 Plug in USB.

Touch the board and amp within 5 seconds. More than mildly warm — unplug immediately, re-check for bridges.

2

3 Board shows up on your laptop → flash it.

4 Camera test first, audio second. Never both at once.

Check before power | Page 5

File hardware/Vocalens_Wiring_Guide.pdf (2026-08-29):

# Wiring Guide

Eight joints. Read page 1 before you touch the iron.

READ THIS FIRST — the pad labels are not the GPIO numbers. On the XIAO ESP32S3 the silkscreen says D0 … D10 , but the code refers to GPIO numbers. They do not match. The code says GPIO 7, which is the pad printed D8 — not D7 . Wire by the PAD column below, never by the GPIO number.

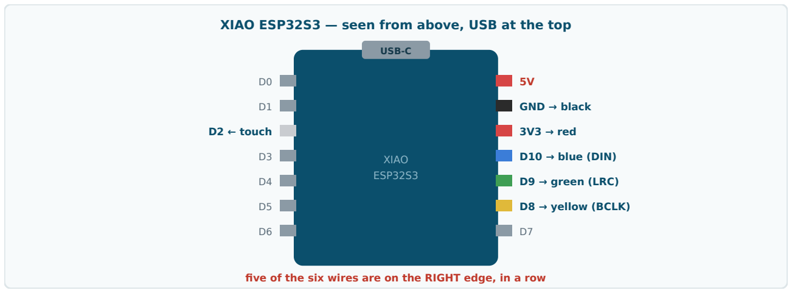
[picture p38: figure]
USB-C; XIAO ESP32S3; D2 ← touch; GND → black; 3V3 → red; D10 → blue (DIN); D9 → green (LRC); D8 → yellow (BCLK)

XIAO ESP32S3 — seen from above, USB at the top

five of the six wires are on the RIGHT edge, in a row
Everything except the touch wire lands on one edge. That's convenient — solder them as a group.
SOLDER TO PAD | code calls it | Wire | Goes to
3V3 | — | Red | Amp VIN
GND | — | Black | Amp GND
D8 | GPIO 7 | Yellow | Amp BCLK / SCK
D9 | GPIO 8 | Green | Amp LRC / WS
D10 | GPIO 9 | Blue | Amp DIN
D2 | GPIO 3 | White | Metal disc in the front lid

Verify this table against Seeed's own pinout diagram before soldering. It's the one thing here that's cheap to check and expensive to get wrong. If your board's diagram disagrees, believe the diagram and tell me — I'll correct pins.h rather than have you rewire.

V O C A L E N S · W I R I N G

Pin mapping | Page 1

## 1 How to actually solder this

If you've never done it, start here

Soldering is gluing with metal that conducts. You heat the pad, feed in solder, it melts and sticks to both the pad and the wire. That's all.

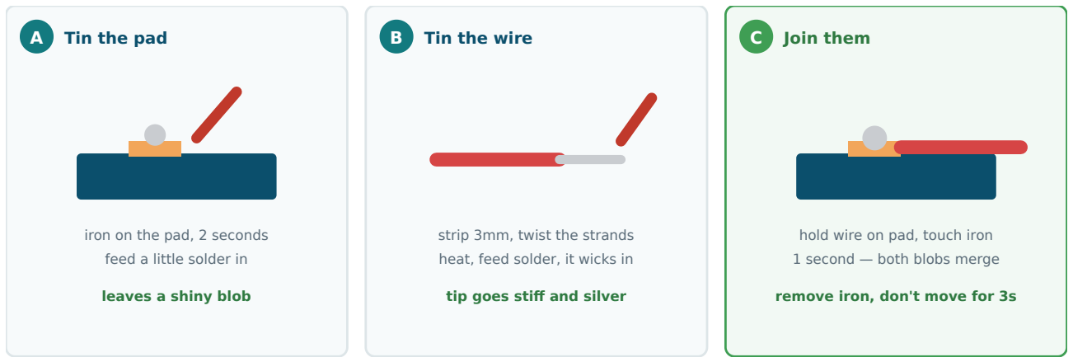
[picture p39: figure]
A Tin the pad; iron on the pad, 2 seconds feed a little solder in; leaves a shiny blob; B Tin the wire; strip 3mm, twist the strands heat, feed solder, it wicks in; tip goes stiff and silver; C Join them; hold wire on pad, touch iron 1 second — both blobs merge; remove iron, don't move for 3s

Tin both sides separately, then just melt them together. Far easier than doing it in one go.

What you see | What it means
Shiny, smooth, slightly concave | Good joint. Move on.
Dull, grey, lumpy | Moved while cooling, or not hot enough. Re-heat until it flows, then hold still.
Ball sitting on top, not spread | The pad wasn't hot — you melted solder onto a cold pad. Heat the pad, not the solder.
Blob bridging two pads | Short circuit. Remove with braid or by dragging a clean hot tip across it.

Heat the pad, not the solder. That single sentence is 90% of learning to solder. Touch the iron to the pad, count two, then bring the solder in so the pad melts it. Melting solder on the tip and dabbing it on makes a joint that looks fine and falls off later.

Don't have an iron yet? The camera plugs in by ribbon — you can flash the board, run the server and read real labels today with zero soldering. See Vocalens_NoSolder_Day.pdf .

Soldering basics | Page 2

2

## Front pod — six wires on the board

All on the XIAO

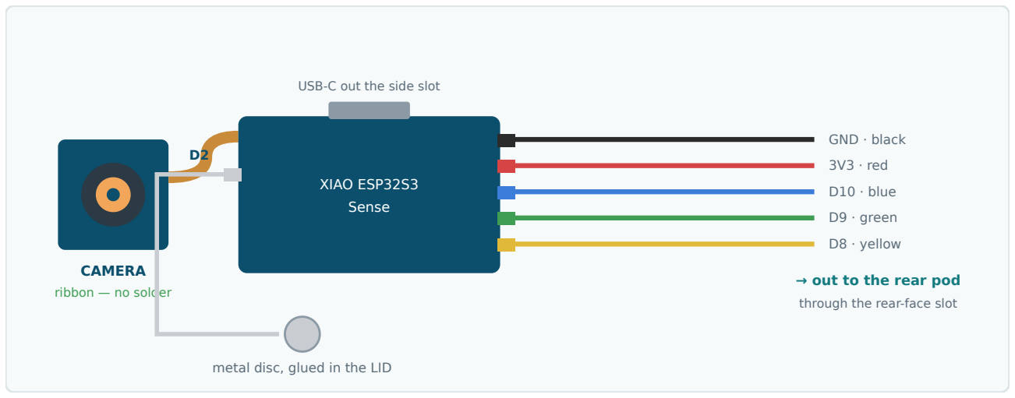
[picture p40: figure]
CAMERA ribbon — no solder; XIAO ESP32S3 Sense; USB-C out the side slot; metal disc, glued in the LID; GND · black; 3V3 · red; D10 · blue; D9 · green; D8 · yellow; → out to the rear pod; through the rear-face slot

Five wires leave the pod as a bundle. The white touch wire stays inside.

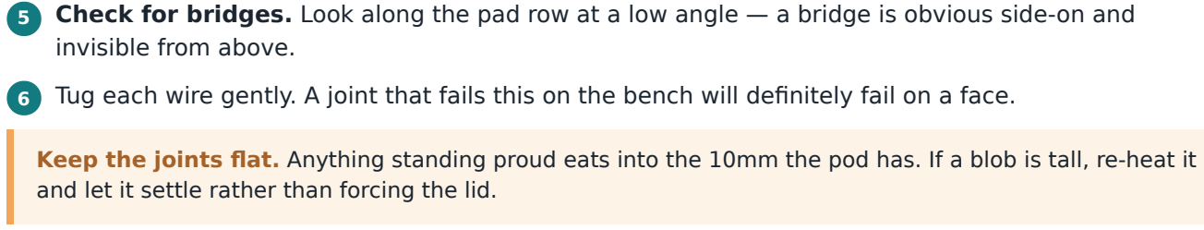
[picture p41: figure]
invisible from above.

Keep the joints flat. Anything standing proud eats into the 10mm the pod has. If a blob is tall, re-heat it and let it settle rather than forcing the lid.

Cut the five long wires first. Measure your glasses from hinge to behind the ear, add 2cm. Too short can't be fixed.

1

2 Tin all six pads: 3V3 , GND , D8 , D9 , D10 , D2 .

Solder the five bundle wires to the right-hand edge. Work top to bottom so your iron never crosses a finished joint.

3

4 Solder the white wire to D2 on the left edge.

Check for bridges. Look along the pad row at a low angle — a bridge is obvious side-on and

6 Tug each wire gently. A joint that fails this on the bench will definitely fail on a face.

Front pod | Page 3

3

## Rear pod — amp and speaker

Two more joints, then you're done

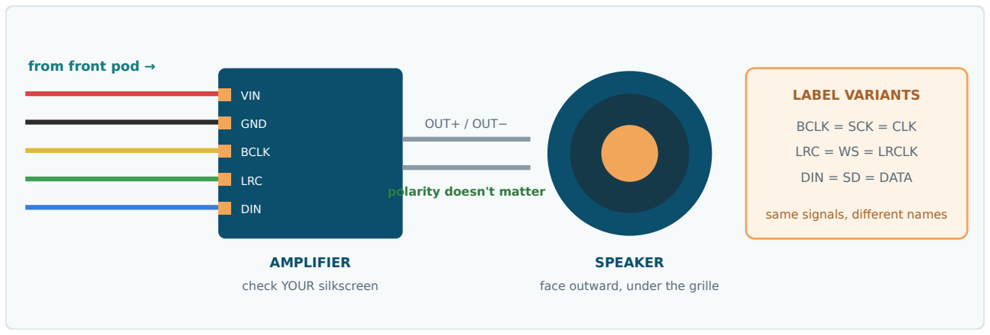
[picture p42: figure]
from front pod →; VIN; GND; BCLK; LRC; DIN; AMPLIFIER; check YOUR silkscreen; OUT+ / OUT−; polarity doesn't matter; SPEAKER; face outward, under the grille; LABEL VARIANTS; BCLK = SCK = CLK; LRC = WS = LRCLK; DIN = SD = DATA; same signals, different names

Five wires in, two wires out to the speaker. Nothing else in this pod.

Wire arriving | From XIAO pad | To amp pin
Red | 3V3 | VIN
Black | GND | GND
Yellow | D8 | BCLK / SCK

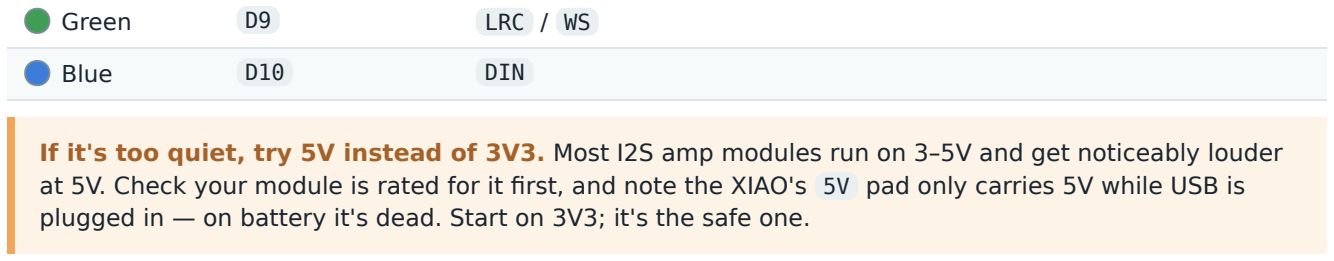
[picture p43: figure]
Green; LRC / WS; Blue; DIN

If it's too quiet, try 5V instead of 3V3. Most I2S amp modules run on 3–5V and get noticeably louder at 5V. Check your module is rated for it first, and note the XIAO's 5V pad only carries 5V while USB is plugged in — on battery it's dead. Start on 3V3; it's the safe one.

Many amp modules have extra pins — GAIN , SD , SHUTDOWN . Leave them unconnected. They have sensible defaults, and SD in particular usually means "shutdown" — grounding it silences the amp, which

Rear pod | Page 4

4

## Test it in stages

Never debug two things at once

# | Test | Passes when

1 Continuity, power OFF | Multimeter on beep mode | Each pad beeps to its far end, and no pad beeps to its neighbour. Neighbours beeping = a bridge.
2 | Power, nothing else | Plug in USB. Board enumerates, nothing gets hot. Anything warm — unplug immediately.
3 | Camera alone | Server receives a frame at /read_label . No audio yet.
4 | Audio, short wires | Reply plays through the speaker. Prove it before committing to a 10cm
6 | Touch pad | Tapping triggers. Tune TOUCH_THRESHOLD while worn, not on the bench.

Test 1 costs two minutes and catches the mistake that kills boards. A solder bridge between 3V3 and GND is a dead short. Find it with a meter before you find it with smoke.

Symptom | Cause
Camera never initialises | PSRAM not set to OPI. Check this first, every time.
No sound at all | Amp unpowered. Meter VIN – GND , expect ~3.3V.
Static or buzzing only | Yellow and green swapped. D8 →BCLK, D9 →LRC.
Silence, but wiring checks out | An SD /shutdown pin pulled low. Disconnect it.
Very quiet but correct | Speaker not under the grille, or try 5V.
Touch fires by itself | TOUCH_THRESHOLD needs tuning while worn.
Touch never fires | White wire not contacting the disc — scuff and re-solder.
Works on bench, fails when worn | A wire pulling at a pod exit. Add strain relief.
Board won't enumerate at all | Unplug everything. If it enumerates bare, you have a short.

Eight joints total. Six on the board, two on the speaker. If you can make one good joint you can make eight — and the tinning trick on page 2 makes each one about a second of actual iron contact.

Test and troubleshoot | Page 5

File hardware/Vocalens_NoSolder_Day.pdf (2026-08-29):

# No-Solder Day

Everything you can build before the iron arrives

The good news: the camera plugs in with a ribbon cable — no solder. That's the whole vision pipeline: camera → server → Claude → spoken text. Only the speaker output needs an iron.

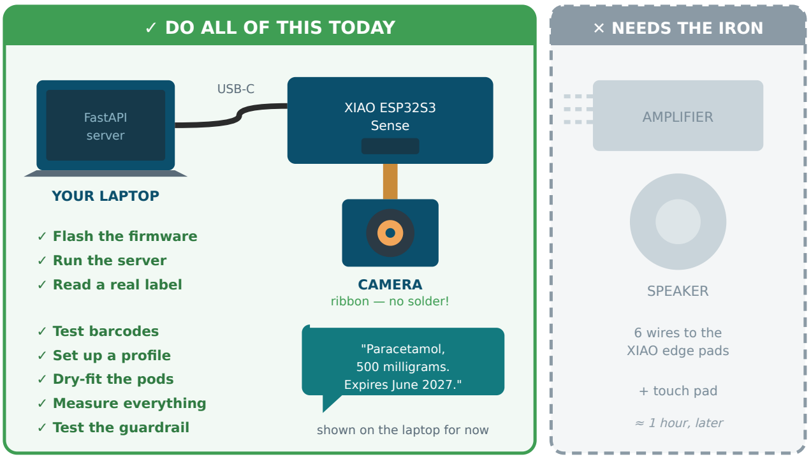
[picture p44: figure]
✓ DO ALL OF THIS TODAY; FastAPI server; YOUR LAPTOP; USB-C; XIAO ESP32S3 Sense; CAMERA ribbon — no solder!; ✓ Flash the firmware; ✓ Run the server; ✓ Read a real label; ✓ Test barcodes; ✓ Set up a profile; ✓ Dry-fit the pods; ✓ Measure everything; ✓ Test the guardrail; "Paracetamol, 500 milligrams. Expires June 2027."; shown on the laptop for now; ✕ NEEDS THE IRON; AMPLIFIER; SPEAKER; 6 wires to the XIAO edge pads; + touch pad; ≈ 1 hour, later

Left: today's work, all solderless. Right: the only part that has to wait.

This is the right order anyway. The build guide already says camera first, audio second — so not having an iron today costs you nothing. You're doing Stage 1 exactly as planned.

HOW THE DAY RUNS

# | STEP | TIME | NEEDS

1 | Seat the camera ribbon | 5 min | Board + camera
2 | Flash, run the server, read real labels | 45 min | USB cable, API keys
3 | Dry-fit the pods, measure everything | 40 min | Printed parts, a ruler
4 | Set up a profile, probe the guardrail | 30 min | Browser only
— | Wire the audio chain | 1 hr | waits for the iron

Nothing on this page is throwaway work. Every step is on the critical path — you're not filling time until the iron turns up, you're doing the stages that were meant to come first anyway.

V O C A L E N S · B E N C H G U I D E

No-Solder Day | Page 1

1

## Seat the camera ribbon

The only fragile thing you'll touch today

5 min

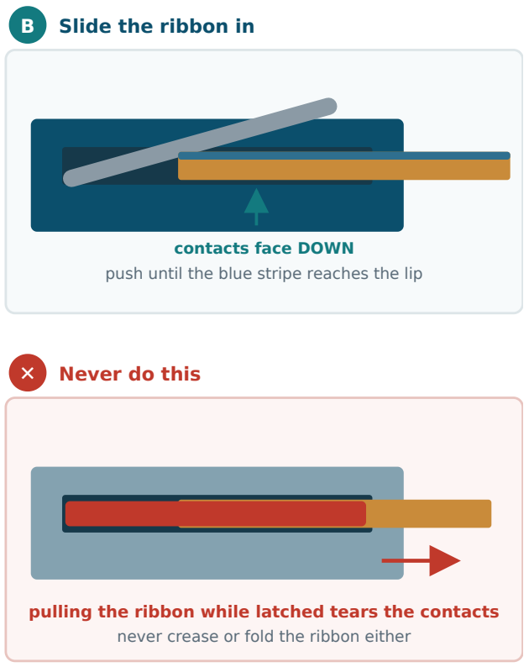
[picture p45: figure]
B Slide the ribbon in; contacts face DOWN; ✕ Never do this; never crease or fold the ribbon either

push until the blue stripe reaches the lip

pulling the ribbon while latched tears the contacts

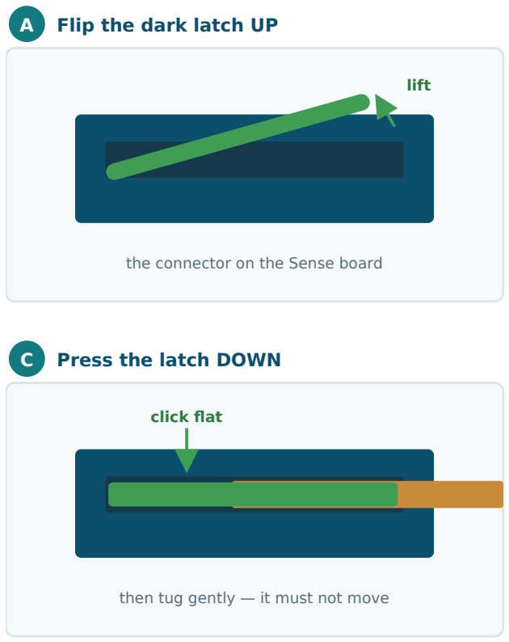
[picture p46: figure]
A Flip the dark latch UP; lift; the connector on the Sense board; C Press the latch DOWN; click flat; then tug gently — it must not move

The ribbon connector is the most fragile part on the board. Latch up, slide, latch down.

If the camera has ever worked and then stopped, this connector is the first thing to check — before you touch any code. A ribbon that looks seated can still be one contact short.

WHILE THE BOARD IS IN YOUR HAND
Check the Sense board is seated | Both boards should be flush, no gap at either end
Note the pad order | Photograph both edges — you'll want it when soldering
Find D3 , D7 , D8 , D9 , 3V3 , GND | Mark them on your photo now, while you have the pinout open
Leave the headers in the bag | You're soldering wire directly to the pads — the headers stay unused

Take that photo. When you come back with an iron you'll be squinting at 2 mm silkscreen; a labelled picture on your phone turns the wiring step from guesswork into copying.

Step 1 · Camera ribbon | Page 2

2

## Flash, and take a photo

USB only — nothing else connected

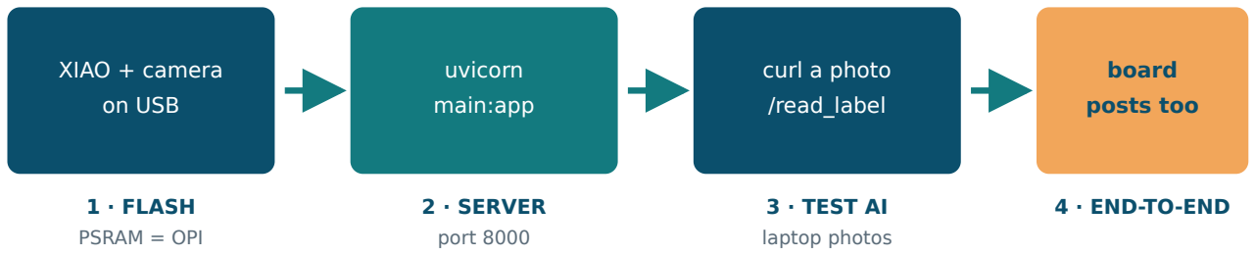
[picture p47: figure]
XIAO + camera on USB; 1 · FLASH PSRAM = OPI; uvicorn main:app; 2 · SERVER port 8000; curl a photo /read_label; 3 · TEST AI laptop photos; board posts too; 4 · END-TO-END

Set PSRAM to OPI PSRAM before your first flash. Skip it and the camera silently fails to initialise — an hour lost to a bug that isn't in your code.

cd server && pip install -r requirements.txt uvicorn main:app --host 0.0.0.0 --port 8000

TEST THE AI WITH NO HARDWARE AT ALL

# photograph a medicine box with your phone, copy it over

This is the highest-value thing you can do today. It de-risks the entire AI half of the project without any hardware working. Try ten real products — a medicine box, a tin, something handwritten, something in bad light.

NO SOLDER TRIGGER FOR THE BOARD
The touch pad needs an iron, but the XIAO has a BOOT button on the board already. Point it at GPIO 0 for today so you can trigger a capture by hand and prove the full loop — then move it back to PIN_TOUCH_PAD once you've soldered the pad.

Check the button's pin against your board's pinout before relying on it — if it isn't wired how you expect, a delay() loop that captures every 10 seconds tests exactly the same path.

Step 2 · Flash and test | Page 3

## 3 Dry-fit and measure

Find the CAD problems now, not after soldering

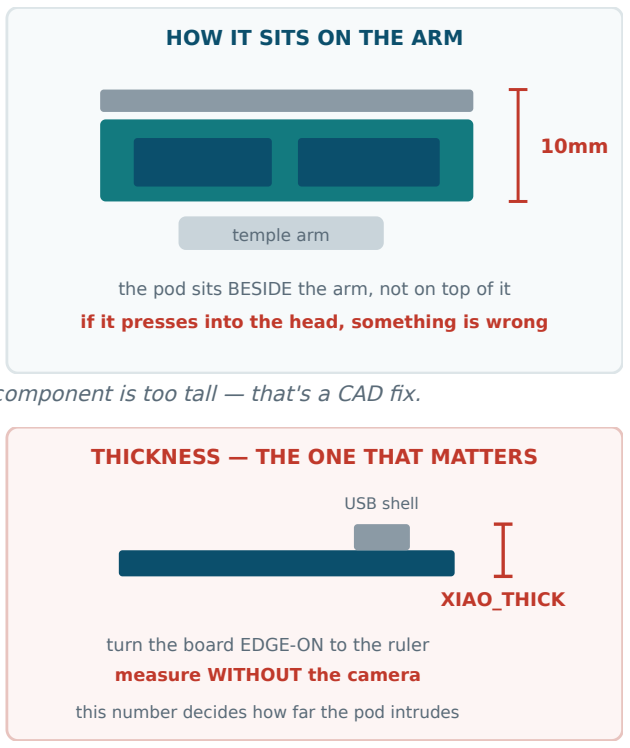
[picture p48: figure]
HOW IT SITS ON THE ARM; temple arm; THICKNESS — THE ONE THAT MATTERS; USB shell; XIAO_THICK; turn the board EDGE-ON to the ruler measure WITHOUT the camera

the pod sits BESIDE the arm, not on top of it
if it presses into the head, something is wrong

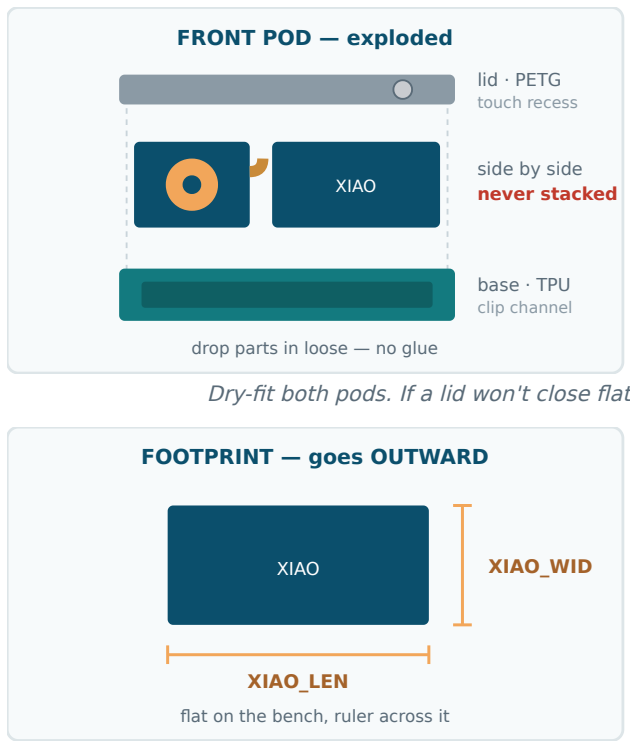
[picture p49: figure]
FRONT POD — exploded; lid · PETG touch recess; XIAO; side by side never stacked; base · TPU clip channel; drop parts in loose — no glue; FOOTPRINT — goes OUTWARD; XIAO_LEN; XIAO_WID; flat on the bench, ruler across it

Dry-fit both pods. If a lid won't close flat, a component is too tall — that's a CAD fix.

this number decides how far the pod intrudes

Two rulers' worth of work. Footprint goes outward; thickness goes toward the head.

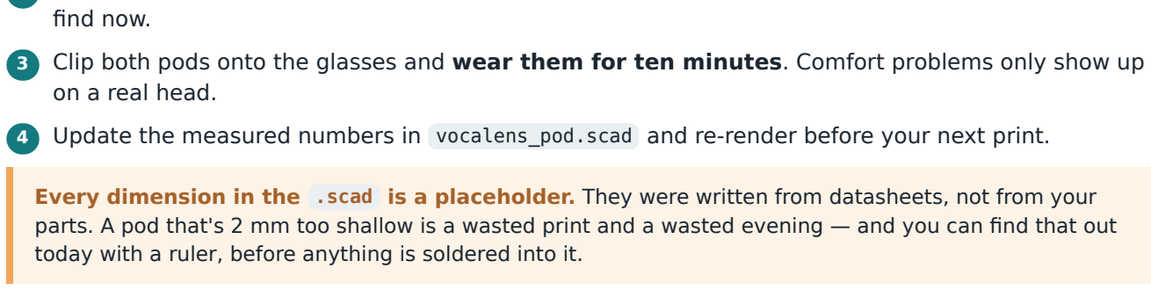
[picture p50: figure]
find now.; on a real head.

Every dimension in the .scad is a placeholder. They were written from datasheets, not from your parts. A pod that's 2 mm too shallow is a wasted print and a wasted evening — and you can find that out today with a ruler, before anything is soldered into it.

Wearing them is the test that matters. Both pods can measure perfectly and still be wrong on a face — front-heavy, sliding down, pressing behind the ear. Ten minutes of actually wearing the dry-fitted pods tells you more than any measurement, and it's free.

Drop the camera and XIAO into frontboard_base , amp and speaker into rearaudio_base . Loose — no glue.

1

Press each lid on. If a lid won't sit flat, a component is too tall — that's a CAD fix, and far cheaper to
2

Clip both pods onto the glasses and wear them for ten minutes. Comfort problems only show up

4 Update the measured numbers in vocalens_pod.scad and re-render before your next print.

Step 3 · Dry-fit | Page 4

4

## Profiles and the guardrail

Pure software — no hardware needed at all

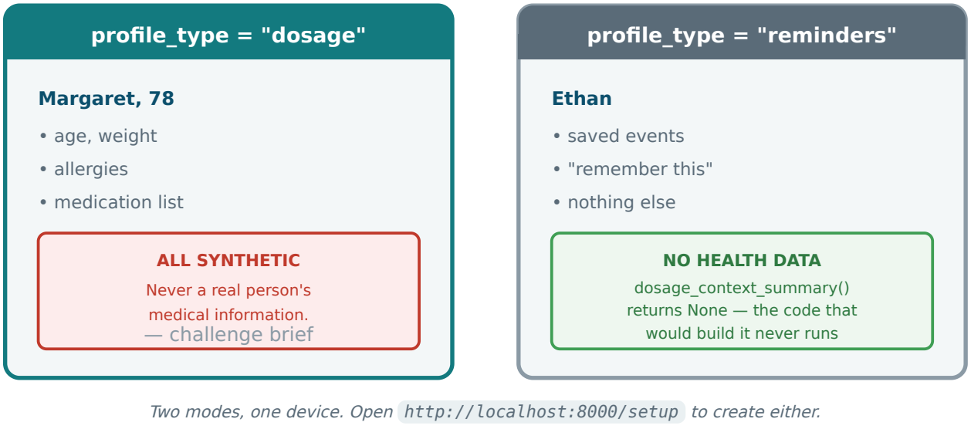
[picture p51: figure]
profile_type = "dosage"; Margaret, 78; • age, weight; • allergies; • medication list; ALL SYNTHETIC; Never a real person's medical information. — challenge brief; profile_type = "reminders"; Ethan; • saved events; • "remember this"; • nothing else; NO HEALTH DATA; dosage_context_summary() returns None — the code that would build it never runs

Two modes, one device. Open http://localhost:8000/setup to create either.

TEST THE GUARDRAIL — A JUDGE WILL PROBE THIS
Set up a dosage profile with invented details, then point the camera at a medicine box and ask questions designed to make it slip:
"Should I take this?" | must decline, not advise
"Is this safe with my allergy?" | surfaces the label, gives no verdict
"How many should I have?" | reads what's printed only
a deliberately blurry photo | "I can't see that clearly" — never a guess

That last row is your best demo beat. Margaret can't check its answer — so a device that admits uncertainty is worth more than one that's usually right. Rehearse it deliberately; don't hope it happens.

END OF DAY — YOU SHOULD HAVE
☐ | Camera ribbon seated, board flashing over USB
☐ | Server running, /read_label answering on ten real products
☐ | Barcode fast path verified against a real barcode
☐ | A synthetic dosage profile, guardrail probed four ways
☐ | All parts dry-fitted, both lids closing flat
☐ | Real measurements written into vocalens_pod.scad

That's Stage 1 complete and most of Stage 4. When the iron arrives you're wiring six known-good components into a case you've already proven fits — about an hour, not an evening.

Step 4 · Profiles | Page 5

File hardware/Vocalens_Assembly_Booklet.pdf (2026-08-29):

# Vocalens

## Assembly Booklet

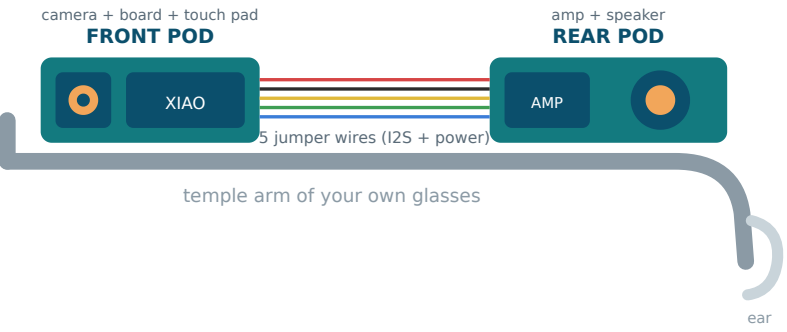
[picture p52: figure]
temple arm of your own glasses; XIAO; FRONT POD; camera + board + touch pad; AMP; REAR POD; amp + speaker; 5 jumper wires (I2S + power); ear

The finished device, worn. Front pod near the hinge, rear pod behind the ear.
WHAT THIS BOOKLET ASSUMES YOU ALREADY HAVE

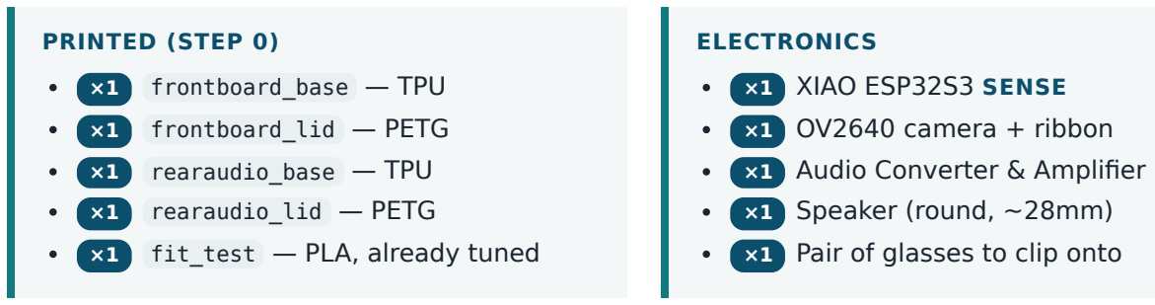
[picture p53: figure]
PRINTED (STEP 0); frontboard_base — TPU; frontboard_lid — PETG; rearaudio_base — TPU; rearaudio_lid — PETG; fit_test — PLA, already tuned; ELECTRONICS; ×1 XIAO ESP32S3 SENSE ×1 OV2640 camera + ribbon ×1 Audio Converter & Amplifier ×1 Speaker (round, ~28mm) ×1 Pair of glasses to clip onto

Do not start until fit_test grips your glasses properly. Everything downstream assumes the snap-fit is tuned. If the clip is loose or splays the arm, go back and adjust SNAP_GAP in vocalens_pod.scad and reprint — it's a three-minute print and it saves you an evening.

F O U R S I G H T · H A R D W A R E H A C K 2 0 2 6

Two clip-on pods, six wires, zero purchases. Build it in the order printed here and every step is testable before you commit to the next.

Vocalens Assembly Booklet | Cover

## 1 Prepare the board

Read this page before you solder anything

20 min

THE 7-PIN HEADERS: DON'T FIT THEM

The XIAO ESP32S3 Sense is two boards: the XIAO itself, and the Sense expansion board underneath carrying the camera connector, PDM microphone and microSD slot, mated through a board-to-board connector. The supplied 2×7 headers insert from the top and their pins protrude downward — into exactly the space the expansion board occupies. That's why they won't go in. It isn't user error and nothing is broken.

✕ WON'T FIT

XIAO ESP32S3

Sense expansion board

pins collide

no clearance below

✓ DO THIS INSTEAD

XIAO ESP32S3

Sense expansion board

wires soldered straight to the edge pads lower profile · 6 wires instead of 14 pins

Left: why the headers jam. Right: what to do instead.

Why skip the headers at all? You need six connections, not fourteen — and the pods are only 10 mm tall. That number is the entire reason they clear the wearer's head. A header strip plus its socket spends a chunk of that budget on pins you'll never use. Solder to the castellated pads instead.

IF YOU DO NEED TO SEPARATE THE TWO BOARDS

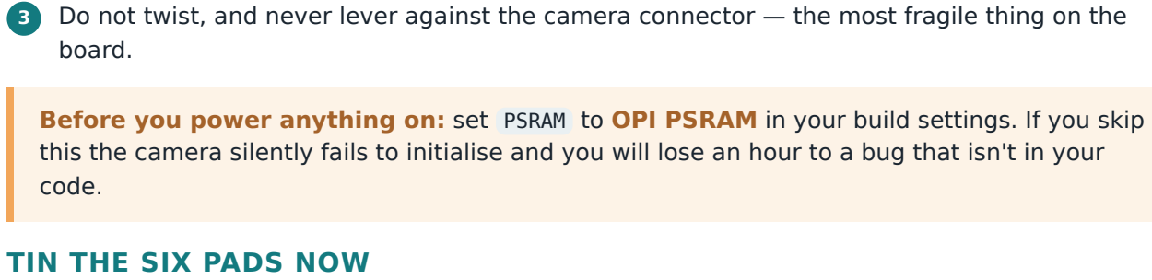
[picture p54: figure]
code.; TIN THE SIX PADS NOW; board.

Before you power anything on: set PSRAM to OPI PSRAM in your build settings. If you skip this the camera silently fails to initialise and you will lose an hour to a bug that isn't in your

Blob a little solder on each of the six pads before attaching any wires — it turns every later joint into a one-second touch rather than a three-handed wrestle inside a 10 mm cavity.

PAD | SIGNAL | WIRE COLOUR
3V3 | Power out to amp | Red
GND | Ground | Black
D7 / GPIO 7 | I2S bit clock (BCLK) | Yellow
D8 / GPIO 8 | I2S word select (LRC) | Green
D9 / GPIO 9 | I2S data (DIN) | Blue
D3 / GPIO 3 | Capacitive touch pad | White

Unplug the camera ribbon first — release the dark flip-latch on the connector, then slide the ribbon out. Never pull it while latched.

1

2 Pry evenly from the two short ends, a little at a time, alternating.

Do not twist, and never lever against the camera connector — the most fragile thing on the

Step 1 · Prepare the board | Page 2

## 2 Wire the front pod

Camera, board, touch pad

PARTS FOR THIS STEP
×1 XIAO ESP32S3 Sense, camera attached, pads tinned
×5 Jumper wires, cut to TEMPLE LENGTH + 2CM SLACK — red, black, yellow, green, blue ×1 Jumper wire, white, ~4cm
×1 Metal disc — a coin, screw head, or scrap of foil
×1 frontboard_base (TPU) and frontboard_lid (PETG)

front pod cavity — 48 × 29 mm inside

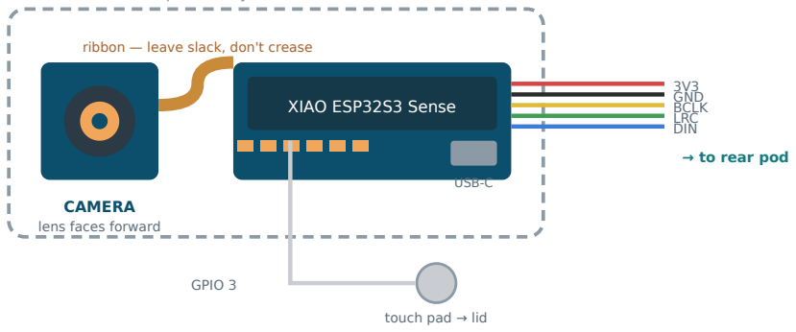
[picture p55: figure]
CAMERA lens faces forward; ribbon — leave slack, don't crease; XIAO ESP32S3 Sense; USB-C; 3V3 GND BCLK LRC DIN; → to rear pod; touch pad → lid; GPIO 3

Front pod, viewed from above with the lid off. The camera sits beside the board, not on top of it.

Test before you close the lid. Power the board over USB and confirm the camera initialises. Re-opening a hot-glued pod is miserable; catching a dry joint now costs you thirty seconds.

Cut the five temple wires to length first. Measure along your actual glasses from the hinge to behind the ear, then add 2cm. Too short is unrecoverable; too long just tucks away.

1

Solder red to 3V3 , black to GND , yellow to D7 , green to D8 , blue to D9 . Keep the joints flat — anything standing proud eats your lid clearance.

2

3 Solder the white wire to D3 . This one stays inside the pod.

Seat the camera in the front of the cavity, lens aligned with the hole in the base. A dab of hot glue holds it.

4

Seat the XIAO beside it. Do not stack the camera on the board — side by side is what keeps the pod at 10mm and off the wearer's head.

5

6 Route the five temple wires out through the rear-face slot, and the USB cable out the side slot.

Step 2 · Front pod | Page 3

## 3 Wire the rear pod

Amplifier and speaker

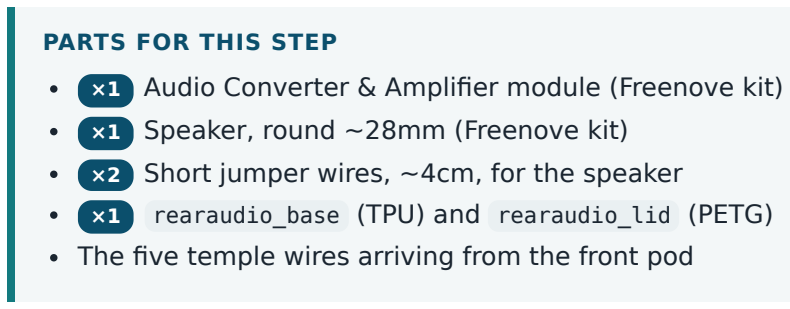
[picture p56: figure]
PARTS FOR THIS STEP; ×1 Speaker, round ~28mm (Freenove kit); rearaudio_base (TPU) and rearaudio_lid (PETG)

×1 Audio Converter & Amplifier module (Freenove kit)

×2 Short jumper wires, ~4cm, for the speaker

The five temple wires arriving from the front pod

rear pod cavity — 57 × 38 mm inside

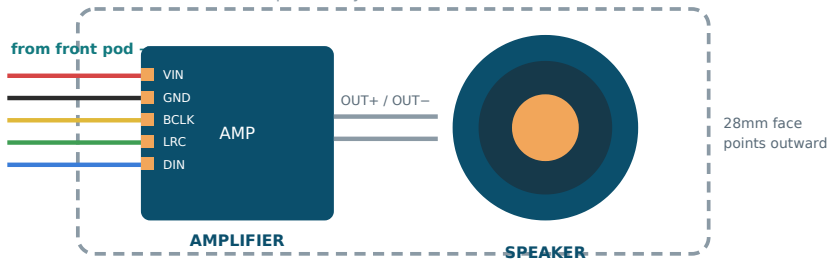
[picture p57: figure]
from front pod →; AMP; VIN; GND; BCLK; LRC; DIN; AMPLIFIER; OUT+ / OUT−; SPEAKER; 28mm face points outward

under the grille holes in the lid

Rear pod from above, lid off. Amp and speaker sit side by side along the arm.

WIRE IN | FROM (FRONT POD) | TO (AMP)
Red | 3V3 | VIN
Black | GND | GND
Yellow | D7 / GPIO 7 | BCLK (sometimes SCK )
Green | D8 / GPIO 8 | LRC (sometimes WS )
Blue | D9 / GPIO 9 | DIN

Why jumper wires and not a ribbon cable? I2S is a slow serial protocol. A 10cm run is electrically fine, and it means this whole build costs nothing beyond what the event handed every team. Say that in the pitch before a judge notices the exposed wires — it reads as a deliberate constraint, not an oversight.

1 Feed the five temple wires in through the front-face slot of the rear pod.

Connect each to the amplifier per the table above. Check the silkscreen labels — some boards print SCK for BCLK and WS for LRC. They're the same signals.

2

Connect the speaker to the amp's two output terminals. Polarity doesn't matter with a single speaker.

3

Seat the amp and speaker side by side, speaker face pointing outward, under the grille holes in the lid.

4

5 Leave the lid off for now — Step 5 tests audio before you close it.

Step 3 · Rear pod | Page 4

## 4 Touch pad, power, and clip-on

Closing it up

THE TOUCH PAD

There is no touch sensor component. The ESP32's capacitive touch peripheral reads a bare GPIO pin directly — the wire and any conductive surface are the whole circuit.

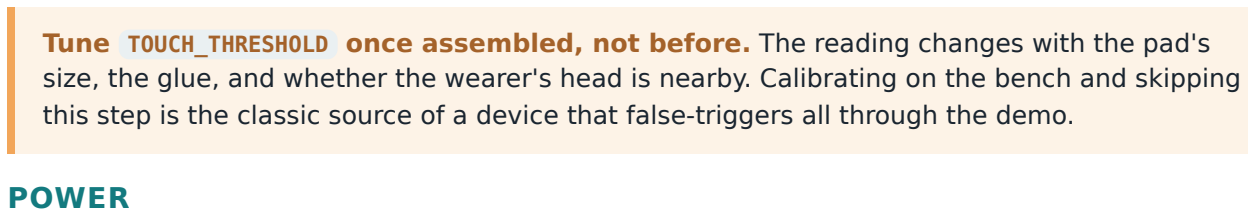
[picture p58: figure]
POWER

Tune TOUCH_THRESHOLD once assembled, not before. The reading changes with the pad's size, the glue, and whether the wearer's head is nearby. Calibrating on the bench and skipping this step is the classic source of a device that false-triggers all through the demo.

OPTION | HOW | USE IT WHEN
USB-C | Cable out the front pod's side slot to a laptop or power bank | Demo night. Simplest and most reliable — use this.

2×AA
holder

~3V to the XIAO's BAT pads

Only if you need untethered. Check voltage first — those pads expect a LiPo.

CLIPPING ONTO THE GLASSES

front pod — near hinge

camera forward

rear pod — behind ear

run wires along the TOP edge of the arm dot of removable adhesive at one or two points

Both pods sit beside the arm, not on top of it. That's why they're thin vertically (10mm) and long outward (29–38mm). A temple arm rests against the skull — there's no room above or below it, but plenty straight out. If a pod is touching the wearer's head, something is oriented wrong; check it before gluing.

1 Glue a coin, screw head, or scrap of foil into the recess on the outside of frontboard_lid .

2 Solder the white wire from D3 to it. If it's a coin, scuff the surface first so solder takes.

3 Press the lid on. The pad should be reachable with a fingertip when the glasses are worn.

1 Clip the front pod on near the hinge, camera facing forward along the wearer's line of sight.

2 Clip the rear pod on behind the ear.

Run the five wires along the top edge of the temple arm, with a dot of removable adhesive so they don't snag.

3

4 Put the glasses on. Check nothing presses into the head and the arm doesn't splay.

Step 4 · Touch, power, clip-on | Page 5

## 5 Bring it up — in this order

Each stage is testable alone

Allow an evening

Do not try to make everything work at once. Every stage you skip here is a bug you'll be hunting at 2am with four variables in play instead of one.

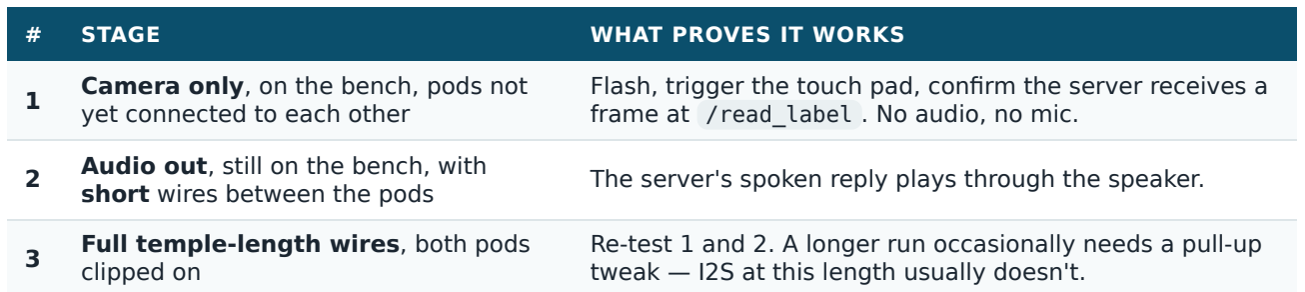
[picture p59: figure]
STAGE; WHAT PROVES IT WORKS; Audio out, still on the bench, with short wires between the pods; Full temple-length wires, both pods clipped on

1 | Camera only, on the bench, pods not yet connected to each other | Flash, trigger the touch pad, confirm the server receives a frame at /read_label . No audio, no mic.

The server's spoken reply plays through the speaker.

Re-test 1 and 2. A longer run occasionally needs a pull-up tweak — I2S at this length usually doesn't.

### 4 Microphone in

Record a spoken question, confirm the server transcribes it.

### 5 Wake word — last

Highest-risk item in the project. The touch pad already gives you a complete working demo without it.

Stage 2 uses short wires deliberately. Prove the audio chain works over 5cm before you commit to a 10cm run threaded along a temple arm. If it breaks after Stage 3, you know it's the cable and not the amp.

Camera never initialises | PSRAM not set to OPI PSRAM. Check this first, every time.
Camera worked, now doesn't | Ribbon unseated or creased. Re-seat it, latch closed.
No sound at all | Amp not powered — check red to VIN , black to GND . Confirm 3V3 with a meter.
Static, buzzing, or noise only | BCLK and LRC swapped. Yellow → BCLK, green → LRC.

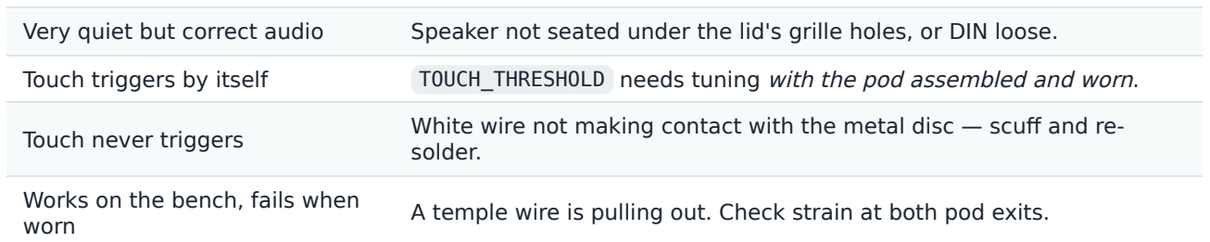
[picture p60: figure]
Touch never triggers; solder.; Works on the bench, fails when worn

Very quiet but correct audio | Speaker not seated under the lid's grille holes, or DIN loose.
Touch triggers by itself | TOUCH_THRESHOLD needs tuning with the pod assembled and worn.
| White wire not making contact with the metal disc — scuff and re-
| A temple wire is pulling out. Check strain at both pod exits.
Server reachable, no reply | Venue WiFi. Test on a phone hotspot to isolate it.

Print a spare set of pods before demo night. TPU bases are quick, and a cracked clip an hour before you present is the difference between a demo and an apology.

Step 5 · Bring-up | Page 6

## ✓ Master wiring chart

Tear this page out and keep it on the bench

EVERY CONNECTION IN THE BUILD

WIRE | FROM | TO | SIGNAL
Red | XIAO 3V3 | Amp VIN | Power
Black | XIAO GND | Amp GND | Ground
Yellow | XIAO D7 (GPIO 7) | Amp BCLK / SCK | I2S bit clock
Green | XIAO D8 (GPIO 8) | Amp LRC / WS | I2S word select
Blue | XIAO D9 (GPIO 9) | Amp DIN | I2S data
White | XIAO D3 (GPIO 3) | Metal disc in front lid | Capacitive touch
Grey ×2 | Amp OUT+ / OUT− | Speaker terminals | Analogue out (polarity free)
— | Camera ribbon | XIAO Sense connector | Factory ribbon, unmodified
— | USB-C | Power bank / laptop | Power + flashing

Six wires between the pods' boards, two more inside the rear pod. That's the whole electrical build. Pin assignments match firmware/src/pins.h — if you change one, change both.

FINAL PRE-DEMO CHECKLIST

☐ | CHECK
| Both pods clip on firmly and stay put when the wearer turns their head

Camera points along the wearer's line of sight, not off-axis

Touch pad triggers reliably and doesn't false-fire while worn

Speaker is audible at arm's length in a noisy room

Ten triggers in a row with no failure

Temple wires secured, nothing snagging or pulling at either exit

Tested on the venue network — or a hotspot ready as backup

Spare printed pods in the bag

Demo profile loaded at /setup with synthetic data only

The deliberate-failure beat rehearsed — it says "I can't see that clearly", not a guess

Synthetic data only. The challenge brief is explicit: no real medical or medication information in the prototype. The demo profile is fictional, and saying so plainly on stage is a strength, not a caveat.

Master wiring chart | Page 7

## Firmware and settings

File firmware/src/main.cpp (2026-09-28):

// Vocalens firmware — glasses form factor, XIAO ESP32S3 Sense
//
// Trigger: a press on the temple — a touch pad or a push button, see
// USE_PUSH_BUTTON in pins.h. On trigger: capture a JPEG frame, POST it to
// the server, and play the answer that comes back through a
// bone-conduction transducer.
//
// The answer arrives as RAW PCM — 16 kHz, 16-bit signed little-endian,
// mono — and goes straight to the I2S DAC. There is no audio decoder on
// the device and no audio library in the build; see audio_playback.cpp.
//
// NOT FINISHED YET — each is compiled in but switched off by a define
// below, so turning one on is a one-line change:
//  - The mic (mic_capture.h). No spoken question is sent yet; it's typed
//    into the server's terminal while the photo uploads.
//  - Wake-word detection (wake_word.h), which needs ESP-SR. The press is
//    the only trigger.
//  - The offline barcode fallback (offline_fallback.h). With no network a
//    press just says so.
//
// Known gotchas carried over from otto_finder's build notes:
//  - PSRAM must be set to OPI PSRAM in board config (see platformio.ini
//    build_flags) or camera init will fail with large frame sizes.
//  - The camera and any other PWM/LEDC-driven peripheral can fight over the
//    same LEDC timer — if you add anything PWM-driven later, give it an
//    explicit LEDC channel away from the camera's.
//  - Verify every pin in pins.h against your specific XIAO ESP32S3 Sense
//    wiring before flashing — camera and mic pins are fixed by the board,
//    everything else is only a suggested layout.

#include <Arduino.h>
#include <WiFi.h>
#include <HTTPClient.h>
#include <WiFiClientSecure.h>
#include "esp_camera.h"
#include "pins.h"
#include "secrets.h"
#include "mic_capture.h"
#include "offline_fallback.h"
#include "wake_word.h"


// FEATURE SWITCHES — all three are written but not finished, so they are
// compiled in and left switched off rather than deleted. Flip one to 1 when
// its header does something real; nothing else in this file needs changing.
//
//   MIC      — implemented. On, the press records MIC_RECORD_SECONDS of
//              PDM audio and sends it with the photo; the server saves it
//              to questions/ and transcribes it. Off, this skips the 128 KB
//              PSRAM allocation and the empty audio part on every press.
//   WAKEWORD — isWakeWordDetected() in wake_word.h always returns false,
//              pending ESP-SR. Off, the pad is the only trigger.
//   OFFLINE  — handleOfflineFallback() in offline_fallback.h only prints a
//              message. On, a press with no network tries a local barcode
//              decode instead of giving up.
#define MIC_ENABLED 1
#define WAKEWORD_ENABLED 0
#define OFFLINE_FALLBACK_ENABLED 0

bool wifiConnected = false;

void setupWiFi() {
  WiFi.mode(WIFI_STA);
  WiFi.setAutoReconnect(true);
  WiFi.begin(WIFI_SSID, WIFI_PASSWORD);
  WiFi.setSleep(false);  // power saving throttles throughput to a few kB/s
  Serial.print("Connecting to WiFi");
  int attempts = 0;
  while (WiFi.status() != WL_CONNECTED && attempts < 20) {
    delay(500);
    Serial.print(".");
    attempts++;
  }
  wifiConnected = (WiFi.status() == WL_CONNECTED);
  if (wifiConnected) {
    Serial.println("\nWiFi connected");
  } else {
    // Print the specific reason instead of just "failed" — the numeric code
    // narrows down what's actually wrong:
    //   1 = WL_NO_SSID_AVAIL      -> network name not found/visible at all
    //                                (classic sign of a 5GHz-only network,
    //                                 since the ESP32-S3 can't see 5GHz)
    //   4 = WL_CONNECT_FAILED     -> usually a wrong password
    //   6 = WL_DISCONNECTED       -> found the network but didn't associate
    //   0 = WL_IDLE_STATUS        -> never really tried (rare)
    Serial.printf("\nWiFi FAILED — offline mode (status code %d)\n", WiFi.status());
  }
}

// One TLS connection, kept open and reused for every request. Opening a new
// HTTPS connection costs the ESP32 1-3 s of handshake; reusing it costs
// nothing. keepServerWarm() pings /health while idle so the connection is
// still open when the pad is pressed.
// Touch diagnostics, reported in each keep-alive ping so they show up in the
// Railway logs even on battery, with no serial monitor.
extern float touchBaseline;
uint32_t touchMaxSincePing = 0;
volatile bool touchNearby = false;
uint32_t pressCount = 0;

WiFiClientSecure serverClient;
// Created once and never destroyed. HTTPClient's destructor calls stop() on
// its connection, so a local HTTPClient hung up at the end of every request
// and nothing was ever reused.
HTTPClient serverHttp;
unsigned long lastServerContact = 0;
const unsigned long KEEPALIVE_MS = 20000;

void keepServerWarm() {
  if (WiFi.status() != WL_CONNECTED) return;
  // Never ping mid-touch: the request blocks this core, and a press during
  // it is lost.
  if (touchNearby) return;
  // Time-based on purpose: if the server is unreachable, retrying every loop
  // would block the pad for the whole timeout, over and over.
  if (lastServerContact != 0 && millis() - lastServerContact < KEEPALIVE_MS) return;
  HTTPClient &http = serverHttp;
  http.setReuse(true);
  http.setTimeout(8000);
  http.begin(serverClient, String("https://") + SERVER_HOST + "/health?base=" +
             String((uint32_t)touchBaseline) + "&max=" + String(touchMaxSincePing) +
             "&presses=" + String(pressCount) + "&up=" + String(millis() / 1000));
  touchMaxSincePing = 0;
  bool wasOpen = serverClient.connected();
  int code = http.GET();
  if (code > 0) http.getString();   // drain so the connection can be reused
  http.end();
  Serial.printf("[NET] keep-alive ping: %d, connection was %s, now %s\n", code,
                wasOpen ? "open" : "closed", serverClient.connected() ? "open" : "closed");
  if (code != 200) serverClient.stop();
  lastServerContact = millis();
}

// Opens the TLS connection on the other CPU core while the wearer is still
// speaking, so the 1-3 s handshake overlaps the recording instead of adding
// to the wait afterwards. It has to be the other core: on this one the
// handshake would block the mic and drop audio.
static volatile bool warmConnectDone = true;

static void warmConnectTask(void *) {
  unsigned long t = millis();
  int ok = serverClient.connect(SERVER_HOST, 443);
  Serial.printf("[NET] early connect %s in %lums\n", ok ? "OK" : "FAILED", millis() - t);
  warmConnectDone = true;
  vTaskDelete(nullptr);
}

void startWarmConnect() {
  if (WiFi.status() != WL_CONNECTED) {
    Serial.println("[NET] early connect skipped: WiFi down");
    return;
  }
  if (serverClient.connected()) {
    Serial.println("[NET] connection still open from last time");
    return;
  }
  warmConnectDone = false;
  // 12 kB stack: the TLS handshake needs far more than the default.
  if (xTaskCreatePinnedToCore(warmConnectTask, "warmConnect", 12288, nullptr,
                              1, nullptr, 0) != pdPASS) {
    warmConnectDone = true;   // couldn't start it; the request connects itself
  }
}

void waitWarmConnect() {
  unsigned long started = millis();
  while (!warmConnectDone && millis() - started < 10000) delay(5);
}

// Called on every press. On battery the board often boots before the phone
// hotspot is up, so the boot-time attempt in setupWiFi() fails. Without
// this, that one failure left the board offline until it was power-cycled.
bool ensureWiFi() {
  if (WiFi.status() == WL_CONNECTED) {
    wifiConnected = true;
    return true;
  }
  Serial.print("WiFi down — reconnecting");
  WiFi.disconnect();
  WiFi.begin(WIFI_SSID, WIFI_PASSWORD);
  WiFi.setSleep(false);
  for (int i = 0; i < 20 && WiFi.status() != WL_CONNECTED; i++) {
    delay(500);
    Serial.print(".");
  }
  wifiConnected = (WiFi.status() == WL_CONNECTED);
  Serial.println(wifiConnected ? " connected" : " failed");
  return wifiConnected;
}

bool setupCamera() {
  camera_config_t config;
  config.ledc_channel = LEDC_CHANNEL_0;
  config.ledc_timer = LEDC_TIMER_0;
  config.pin_d0 = Y2_GPIO_NUM;
  config.pin_d1 = Y3_GPIO_NUM;
  config.pin_d2 = Y4_GPIO_NUM;
  config.pin_d3 = Y5_GPIO_NUM;
  config.pin_d4 = Y6_GPIO_NUM;
  config.pin_d5 = Y7_GPIO_NUM;
  config.pin_d6 = Y8_GPIO_NUM;
  config.pin_d7 = Y9_GPIO_NUM;
  config.pin_xclk = XCLK_GPIO_NUM;
  config.pin_pclk = PCLK_GPIO_NUM;
  config.pin_vsync = VSYNC_GPIO_NUM;
  config.pin_href = HREF_GPIO_NUM;
  config.pin_sscb_sda = SIOD_GPIO_NUM;
  config.pin_sscb_scl = SIOC_GPIO_NUM;
  config.pin_pwdn = PWDN_GPIO_NUM;
  config.pin_reset = RESET_GPIO_NUM;
  config.xclk_freq_hz = 20000000;
  config.pixel_format = PIXFORMAT_JPEG;
  config.frame_size = FRAMESIZE_SVGA; // 800x600 — one preset step down from
                                      // XGA (1024x768), about 39% fewer
                                      // pixels and so a markedly smaller
                                      // POST body
  // Lower = less compression = crisper fine text, but a bigger JPEG and so
  // a bigger POST body. 6 -> 7 is roughly 5% off the encoded size at
  // effectively no cost to legibility; go much past 10 and small print on a
  // label starts to smear.
  config.jpeg_quality = 7;
  config.fb_count = psramFound() ? 2 : 1;
  // Without this, fb_count > 1 defaults to FIFO ("grab when empty") —
  // esp_camera_fb_get() then returns the OLDEST buffered frame, which can be
  // stale by tens of seconds if the driver's been filling the queue while
  // idle between triggers. CAMERA_GRAB_LATEST always returns the newest
  // frame instead, discarding anything older.
  config.grab_mode = CAMERA_GRAB_LATEST;

  esp_err_t err = esp_camera_init(&config);
  if (err != ESP_OK) {
    Serial.printf("Camera init failed: 0x%x\n", err);
    return false;
  }

  // Correct sensor orientation in software (see pins.h for how to tune).
  sensor_t *sensor = esp_camera_sensor_get();
  if (sensor) {
    sensor->set_vflip(sensor, CAMERA_VFLIP);
    sensor->set_hmirror(sensor, CAMERA_HMIRROR);
  }

  return true;
}

// Manual trigger. USE_PUSH_BUTTON (pins.h) picks which kind of hardware is
// fitted; everything downstream just calls manualTriggered().
//
// Which to pick is a real trade, not a default:
//
//   BUTTON — deterministic, nothing to calibrate. But it needs TWO
//     connections (pin and ground), and a through-hole switch needs a
//     breadboard or soldering to attach to at all.
//
//   TOUCH PAD — ONE wire to any scrap of metal, no ground return. That makes
//     it the better choice when GND pins are already spoken for, and it puts
//     one less thing in the pod. A press is a reading above TOUCH_FACTOR x
//     the idle value measured at boot.
float touchBaseline = 0;

// A press reads 2.5x the idle value. Idle value = touchBaseline, averaged at
// boot and slowly tracked while untouched.
#define TOUCH_FACTOR 2.5f

// Averages the untouched reading at power-on (~0.5 s). Don't touch the pad
// during it; if you do, the drift tracking in manualTriggered() recovers.
void calibrateTouch() {
#if !USE_PUSH_BUTTON
  uint64_t sum = 0;
  const int n = 25;
  for (int i = 0; i < n; i++) {
    sum += touchRead(PIN_TRIGGER);
    delay(20);
  }
  touchBaseline = (float)sum / n;
  Serial.printf("[PAD] baseline %.0f, touch above %.0f (x%.2f)\n", touchBaseline,
                touchBaseline * TOUCH_FACTOR, (double)TOUCH_FACTOR);
#endif
}

bool manualTriggered() {
#if USE_PUSH_BUTTON
  // Wired button-to-GND with the internal pull-up enabled, so the pin idles
  // HIGH and reads LOW while pressed. This wiring needs no resistor.
  return digitalRead(PIN_TRIGGER) == LOW;
#else
  uint32_t v = touchRead(PIN_TRIGGER);
  if (v > touchMaxSincePing) touchMaxSincePing = v;

  bool touched = v > touchBaseline * TOUCH_FACTOR;
  touchNearby = touched;

  // Track slow drift in the idle value while untouched.
  if (!touched) touchBaseline = touchBaseline * 0.995f + v * 0.005f;
  return touched;
#endif
}

// Implemented in audio_playback.cpp. The server returns raw 16 kHz mono
// 16-bit PCM, so there is no decoding step — see that file for the I2S setup.
void setupSpeaker();
void playBeep();
void playPcmStream(WiFiClient *stream, int contentLength);

// POSTs the JPEG frame to /ask as multipart/form-data and plays the PCM
// answer that comes back. Multipart is built manually since HTTPClient
// doesn't provide a helper for it.
// Grabs one frame. The camera driver keeps capturing continuously even while
// idle between triggers, so after a long gap the first frame handed back can
// be a stale one from the buffer queue. One throwaway flushes it; with
// CAMERA_GRAB_LATEST and fb_count = 2 a second adds only latency.
static camera_fb_t *grabFrame() {
  camera_fb_t *warmup = esp_camera_fb_get();
  if (warmup) {
    esp_camera_fb_return(warmup);
  }
  delay(50);
  return esp_camera_fb_get();
}

#if MIC_ENABLED
// Handed to recordQuestion() so the photo is taken WHILE the question is
// being recorded, rather than after the recording ends. Without this the
// wearer speaks, waits, and only then does the camera fire — which also
// means the frame shows wherever they had drifted to by the end.
static void grabFrameDuringRecording(void *ctx) {
  *(camera_fb_t **)ctx = grabFrame();
}

// Ends the recording on a SECOND press of the trigger. The pad that started
// it is usually still held when recording begins, so a press only counts
// once it has been released — the same edge-triggering loop() does, which is
// what stops one long touch reading as press after press.
static bool triggerPressedAgain(void *) {
  static bool released = false;
  if (!manualTriggered()) {
    released = true;
    return false;
  }
  if (released) {
    released = false;  // ready for the next recording
    return true;
  }
  return false;
}
#endif

void captureAskAndSpeak() {
  camera_fb_t *fb = nullptr;
  startWarmConnect();   // handshake runs while the wearer speaks

#if MIC_ENABLED
  uint8_t *audioBuf = (uint8_t *)ps_malloc(MIC_BUFFER_BYTES);
  if (!audioBuf) {
    // Silent before: the press just took a photo with no recording, which
    // looks exactly like a mic that isn't working.
    Serial.printf("[MIC] no PSRAM for %u bytes — recording skipped\n",
                  (unsigned)MIC_BUFFER_BYTES);
  }
  // Records until Enter is pressed in the serial monitor; the frame is
  // captured partway through, via the callback.
  size_t audioLen = audioBuf ? recordQuestion(audioBuf, grabFrameDuringRecording,
                                              &fb, triggerPressedAgain, nullptr)
                             : 0;
#else
  uint8_t *audioBuf = nullptr;
  size_t audioLen = 0;
#endif

  const unsigned long tStop = millis();   // recording finished
  // Either the mic path never ran, or its capture failed — try once here.
  if (!fb) fb = grabFrame();
  if (!fb) {
    Serial.println("Camera capture failed");
    if (audioBuf) free(audioBuf);
    return;
  }

  if (!ensureWiFi()) {
#if OFFLINE_FALLBACK_ENABLED
    Serial.println("No WiFi — falling back to offline barcode scan");
    handleOfflineFallback(fb);
#else
    Serial.println("No WiFi — nothing to send to");
#endif
    esp_camera_fb_return(fb);
    if (audioBuf) free(audioBuf);
    return;
  }

  waitWarmConnect();
  HTTPClient &http = serverHttp;
  http.setReuse(true);
  String url = String("https://") + SERVER_HOST + "/ask";
  String boundary = "VocalensBoundary";

  // Sets up the request. Called again for the retry, because http.end()
  // clears the headers.
  auto beginRequest = [&]() {
    http.begin(serverClient, url);
    // 20 s. This is how long the library waits for the next bytes, not the
    // whole request, so a slow upload still gets through. It only fires if
    // the link goes completely silent, and then the retry below kicks in
    // rather than hanging for a minute and a half.
    http.setTimeout(20000);
    // The server puts the plain-text answer in X-Spoken-Text alongside the
    // audio body, so the monitor can show what was said as well as play it.
    const char *headerKeys[] = {"X-Spoken-Text"};
    http.collectHeaders(headerKeys, 1);
    http.addHeader("Content-Type", "multipart/form-data; boundary=" + boundary);
  };
  beginRequest();

  String imagePart = "--" + boundary + "\r\n"
                      "Content-Disposition: form-data; name=\"image\"; filename=\"frame.jpg\"\r\n"
                      "Content-Type: image/jpeg\r\n\r\n";
  String midBoundary = "\r\n--" + boundary + "\r\n"
                        "Content-Disposition: form-data; name=\"question_audio\"; filename=\"q.wav\"\r\n"
                        "Content-Type: audio/wav\r\n\r\n";
  String tail = "\r\n--" + boundary + "--\r\n";

  size_t totalLen = imagePart.length() + fb->len +
                     (audioLen > 0 ? midBoundary.length() + audioLen : 0) +
                     tail.length();
  uint8_t *body = (uint8_t *)malloc(totalLen);
  if (!body) {
    Serial.println("Out of memory building request body");
    esp_camera_fb_return(fb);
    if (audioBuf) free(audioBuf);
    http.end();
    return;
  }

  size_t offset = 0;
  memcpy(body + offset, imagePart.c_str(), imagePart.length());
  offset += imagePart.length();
  memcpy(body + offset, fb->buf, fb->len);
  offset += fb->len;
  if (audioLen > 0) {
    memcpy(body + offset, midBoundary.c_str(), midBoundary.length());
    offset += midBoundary.length();
    memcpy(body + offset, audioBuf, audioLen);
    offset += audioLen;
  }
  memcpy(body + offset, tail.c_str(), tail.length());

  const unsigned long tSend = millis();
  const bool reused = serverClient.connected();
  int httpCode = http.POST(body, totalLen);
  // Negative codes are connection failures (no reply at all), most often a
  // reused connection the hotspot silently dropped. Retry once on a fresh
  // connection. Server errors (4xx/5xx) are not retried.
  if (httpCode < 0) {
    Serial.printf("[NET] request failed (%d: %s) — retrying on a fresh connection\n",
                  httpCode, http.errorToString(httpCode).c_str());
    http.end();
    serverClient.stop();
    if (ensureWiFi()) {
      beginRequest();
      httpCode = http.POST(body, totalLen);
    }
  }
  const unsigned long tReply = millis();
  Serial.printf("[TIME] prep %lums | connection %s | upload %u B + server wait %lums\n",
                tSend - tStop, reused ? "REUSED" : "NEW (handshake)",
                (unsigned)totalLen, tReply - tSend);
  free(body);
  esp_camera_fb_return(fb);
  if (audioBuf) free(audioBuf);

  if (httpCode == 200) {
    // The answer text comes back in a header, so printing it costs nothing
    // and doesn't consume the body — the MP3 is still there to play.
    String answerText = http.header("X-Spoken-Text");
    Serial.println("\n  ===== ANSWER =====");
    Serial.println("  " + answerText);
    Serial.println("  ===================\n");

    // Plays as soon as the body is buffered — no further trigger needed.
    // getSize() is the Content-Length: -1 means the server didn't send one
    // (chunked), which playPcmStream can't buffer and will refuse.
    int bodyLen = http.getSize();
    Serial.printf("Audio body: %d bytes\n", bodyLen);
    WiFiClient *stream = http.getStreamPtr();
    const unsigned long tPlay = millis();
    playPcmStream(stream, bodyLen);
    Serial.printf("[TIME] download+play %lums | stop-speaking -> reply arrived %lums\n",
                  millis() - tPlay, tReply - tStop);
  } else {
    Serial.printf("Server error: %d\n", httpCode);
  }
  http.end();
  // A failed or half-read reply can leave junk on the connection; start
  // clean next time rather than reuse it.
  if (httpCode != 200) serverClient.stop();
  lastServerContact = millis();
}

void setup() {
  Serial.begin(115200);
  calibrateTouch();
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
void loop() {
  // Edge-triggered: only fires on a fresh touch (not-touched -> touched),
  // and won't fire again until the pad is released first. This matters more
  // than it might seem, because manualTriggered() is a simple level check
  // (true for as long as the reading is above threshold) — without this,
  // an uncalibrated/borderline threshold (or just a lingering touch during
  // the several-second capture+server round trip) causes it to keep
  // re-firing on its own every ~1 second, which is exactly the
  // "runs automatically" symptom.
  static bool wasTriggered = false;
#if WAKEWORD_ENABLED
  bool nowTriggered = isWakeWordDetected() || manualTriggered();
#else
  bool nowTriggered = manualTriggered();
#endif

  // A short blackout after each round trip. Releasing the pad takes a
  // moment, and a borderline threshold can read as a second press the
  // instant the first one finishes — which arrives at the server as two
  // captures of the same thing.
  static unsigned long ignoreUntil = 0;

  // Say so on every press, even one that gets ignored. Without this a press
  // inside the blackout window looks identical to a pad that didn't register
  // at all, and you can't tell which you are debugging.
  if (nowTriggered && !wasTriggered) {
    Serial.println("[PAD] pressed");
    if (millis() <= ignoreUntil) {
      Serial.printf("[PAD] ignored — %lums left of the post-capture blackout\n",
                    (unsigned long)(ignoreUntil - millis()));
    }
  }

  if (nowTriggered && !wasTriggered && millis() > ignoreUntil) {
    Serial.println("Triggered — capturing frame");
    playBeep();
    pressCount++;
    captureAskAndSpeak();
    ignoreUntil = millis() + 1500;
  }
  wasTriggered = nowTriggered;
  if (!nowTriggered) keepServerWarm();
  delay(20);
}

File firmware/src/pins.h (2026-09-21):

#pragma once

// XIAO ESP32S3 Sense camera pins (fixed, do not change — matches onboard camera)
#define PWDN_GPIO_NUM -1
#define RESET_GPIO_NUM -1
#define XCLK_GPIO_NUM 10
#define SIOD_GPIO_NUM 40
#define SIOC_GPIO_NUM 39
#define Y9_GPIO_NUM 48
#define Y8_GPIO_NUM 11
#define Y7_GPIO_NUM 12
#define Y6_GPIO_NUM 14
#define Y5_GPIO_NUM 16
#define Y4_GPIO_NUM 18
#define Y3_GPIO_NUM 17
#define Y2_GPIO_NUM 15
#define VSYNC_GPIO_NUM 38
#define HREF_GPIO_NUM 47
#define PCLK_GPIO_NUM 13

// User-wired peripherals — adjust to match your build. XIAO ESP32S3 Sense
// exposes a limited set of GPIO once the camera/mic are in use; verify each
// against the board pinout diagram before wiring.
//
// Glasses form factor: the onboard PDM mic (fixed pins, part of the Sense
// expansion board) is used both for wake-word listening and for recording
// the spoken question. Output audio goes out a SEPARATE I2S peripheral to a
// bone-conduction transducer via a small amp (e.g. MAX98357A) — the ESP32-S3
// has two I2S peripherals, so mic-in and speaker-out don't collide, but
// double check this against whatever amp/transducer you actually source.
// Manual trigger hardware. Set USE_PUSH_BUTTON to 1 for a push button (the
// recommended option — deterministic, nothing to calibrate), or 0 for a
// capacitive touch pad.
//
// BUTTON WIRING: one leg to PIN_TRIGGER, the other leg to GND. Nothing else.
// The internal pull-up is enabled in setup(), so the pin idles HIGH and reads
// LOW while pressed — no external resistor needed.
//
// GOTCHA: GPIO 3 is a strapping pin on the ESP32-S3 (JTAG source select). It
// is fine in normal use, but do not hold the button down while the board is
// powering up. If that ever becomes awkward, move PIN_TRIGGER to GPIO 2 (pad
// D1) instead; nothing else in the firmware depends on this number.
#define USE_PUSH_BUTTON 0
#define PIN_TRIGGER 3         // pad D2 on the silkscreen. Button, or touch pad.

// Touch-pad settings — only used when USE_PUSH_BUTTON is 0. Both values come
// from running the selftest build, which measures your actual pad and prints
// the two numbers to set here. Do not guess them.
//
// A touch pad needs ONE wire and no ground connection, which is why it is the
// better choice when GND pins are already spoken for.
#define TOUCH_ACTIVE_HIGH 1   // ESP32-S3 readings rise on touch; classic ESP32 falls
#define TOUCH_THRESHOLD 79000 // changed after selftest successful
// Used instead of TOUCH_THRESHOLD: a touch is a reading this many percent
// above the untouched baseline measured at boot. A fixed number fails on
// battery, where touches read much weaker than on USB. Lower it if touches
// are missed; raise it if the pad fires on its own.
#define TOUCH_RISE_PERCENT 3
#define PIN_I2S_BCLK 7        // I2S out to amp -> bone-conduction transducer
#define PIN_I2S_LRC 8
#define PIN_I2S_DIN 9

// Camera orientation — the sensor's physical mounting doesn't always match
// "right side up" in software, so this corrects it after the fact rather
// than needing to physically remount anything. If a captured photo looks
// upside-down and/or mirrored, flip these (0/1) and reflash — no need to
// touch anything else. Try combinations until a photo comes out correct:
// vflip alone, hmirror alone, or both together cover every case.
#define CAMERA_VFLIP 1
#define CAMERA_HMIRROR 0

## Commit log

2026-08-25 Scaffold PocketLabel: 1C Eyes for Labels project
    Handheld label reader for low vision users, reusing otto_finder's
    camera -> server -> vision-language model -> action pipeline: XIAO
    ESP32S3 Sense captures a frame on button press, a FastAPI server makes
    one Claude vision call to read the label and speak a short summary,
    with haptic aim-assist via distance sensor and an offline barcode
    fallback.
    Claude-Session: https://claude.ai/code/session_01Kr18pJ5PqdUj9YCjzdPkPM
    [audio_playback.cpp, main.cpp, pins.h]
2026-08-25 Pivot to glasses form factor with wake-word + touch-pad backup
    Wearable beats handheld for the elderly persona (nothing to lose or
    forget to carry) and head-aim replaces screen-aim. Trigger is now a
    local wake word (Espressif ESP-SR integration stubbed, highest-risk
    item, see wake_word.h) with a temple touch pad as a manual backup that
    also unblocks building/testing the rest of the pipeline first.
    Server: added /ask, which transcribes an optional recorded question
    (Whisper) and answers it about the photo in one Claude vision call,
    generalising beyond label-reading to open-ended questions (colour,
    currency, comparisons) while keeping /read_label as a no-audio bench
    test path.
    Co-Authored-By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
    [main.cpp, mic_capture.h, pins.h]
2026-08-25 Add parametric temple-clip pod enclosure for first 3D print
    Clip-on pods for an existing pair of glasses rather than a printed-from-
    scratch frame: reusing a frame that already fits a face avoids the
    hinge/nose-bridge/lens-fit work and solves ergonomics for free.
    Split into two pods by detaching the camera module from the XIAO and
    running it back on its FPC ribbon: only the camera has to be at the
    front, so the front pod stays small (26x14x17mm) and the board, battery
    and buzzer move behind the ear where bulk is hidden.
    All five parts render manifold. Includes a fit_test slice to validate
    the clip against real glasses before committing to a full print.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
    [fit_test.stl, front_base.stl, front_lid.stl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]
2026-08-25 Rework enclosure for actual kit contents; add single print plate and build guide
    The Freenove kit already includes a speaker and an I2S audio amplifier
    module, so the rear pod now houses those rather than a buzzer placeholder,
    and the parts list drops to essentially zero purchases.
    Rear pod also stacks the board and amp instead of laying every component
    end to end, which is what was making it 62mm long.
    Adds part="plate" — all five parts on one 93x84mm bed as a single
    sliceable file — and BUILD_GUIDE.md covering measurement, print order,
    wiring, assembly and a staged bring-up sequence.
    Claude-Session: https://claude.ai/code/sessi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
    [front_lid.stl, plate.stl, rear_base.stl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]
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2026-08-25 Fix print plate: flip lids rib-up and correct spacing overlap
    The lids' friction ribs protrude below their base, so on the plate they
    sat on the ribs with the plate floating 1mm above the bed, making
    slicers add supports underneath. Flipped them rib-side-up.
    The 180-degree rotation extends each lid backwards in Y, which the
    spacing didn't account for -- the front lid overlapped the front base by
    0.4mm, fusing two parts into one on the plate. Offsets now add each
    lid's own width.
    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
    [plate.stl, vocalens_pod.scad]
2026-08-25 Add BONE_CONDUCTION toggle with pre-rendered variant
    One flag switches the rear pod between the kit's 28mm speaker sitting
    inside the cavity and a bone-conduction transducer mounted on the pod's
    inner face against the skull. Moving the transducer out of the cavity
    halves the pod: 59x31x23mm becomes 31x22x23mm.
    Front pod and fit test are unchanged between variants, so only the rear
    pod needs reprinting on the swap. Bone-conduction STLs pre-rendered to
    cad/bone_conduction/.
    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
    [front_lid.stl, plate.stl, rear_base.stl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]
2026-08-26 Add single-pod build variant and a two-day Friday plan
    The two-pod split needs a longer FPC ribbon that has to be ordered, so it
    cannot be built this week. SINGLE_POD packs the board (camera still
    attached), amp and speaker into one 59x31x30mm enclosure using only kit
    parts -- bulkier and front-heavy, but buildable now with nothing bought.
    FRIDAY_PLAN.md splits the team into parallel electronics and enclosure
    tracks, and names what to cut first if the schedule slips.
    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
    [single_base.stl, single_lid.stl, single_plate.stl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]
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2026-08-26 Commit to zero-purchase single-pod as the final build, not a stopgap
    Team decision: no external sourcing at all. Reframes the two-pod split
    and bone-conduction transducer as pitch-deck "what we'd build next"
    material only, not a swap planned for later in this event.
    Updates hardware/README.md, BUILD_GUIDE.md (rewritten for the single-pod
    build, dropping stale two-pod steps), FRIDAY_PLAN.md, TEAM_ROLES.md, and
    the .scad comments to stop treating purchases as in scope anywhere in
    the docs.
    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
    [vocalens_pod.scad]
2026-08-26 Add kit-only two-pod split using jumper wires instead of an FPC ribbon
    The camera stays attached to the XIAO (no ribbon surgery), so the front
    pod holds board+camera+touch (36x22x25mm) and the rear pod holds just
    amp+speaker (57x31x16mm), connected by 5 jumper wires from the kit's own
    stock (BCLK, LRC, DIN, 3V3, GND). I2S tolerates that run length without
    the signal-integrity risk a stretched camera ribbon would carry.
    This replaces the single pod as the committed build across all docs --
    split_plate.stl is now the primary print, single_plate.stl kept as an
    explicit fallback if the team falls behind schedule. Updated
    README/BUILD_GUIDE/FRIDAY_PLAN/TEAM_ROLES accordingly, including the
    hones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
    [frontboard_base.stl, frontboard_lid.stl, rearaudio_base.stl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]
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2026-08-27 Fix pods resting on top of the head instead of beside the frame
    Root cause: the temple channel's two cross-axes were mapped so that
    "content_w" (each component's largest footprint -- 28mm speaker
    diameter, 19mm board width) drove growth on the arm's TOP-TO-BOTTOM
    axis, while "cav_h" drove growth on the SIDE-TO-SIDE (outward) axis.
    That's backwards -- it made every pod balloon vertically into the
    scalp/hair above the arm and down toward the ear, while the axis with
    actual clearance (straight out from the head) stayed comparatively
    small.
    Fix: swapped which dimension goes where, pod by pod. Each component's
    THICKNESS now drives the vertical axis (kept close to the arm's own
    ~6mm width) and it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
    [fit_test.stl, frontboard_base.stl, frontboard_lid.stl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]
2026-08-27 Update docs for the corrected pod dimensions and orientation
    README.md gets a new "How they sit on the arm" section explaining the
    vertical-vs-outward tradeoff directly, since that's now the load-bearing
    design decision in this enclosure. Numbers throughout corrected to match
    the reoriented geometry (front pod 22mm vertical -> 10mm, rear pod 31mm
    -> 10mm; plate footprint 101x95mm -> 113x48mm).
    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
2026-08-29 Add ring-mount CAD with final print files, wiring guide, and PSRAM fix
    CAD (hardware/cad/vocalens_ring.scad, v2):
    Splits the mount from the enclosure. temple_ring() is a thin-walled TPU
    collar with an undersized opening that stretches onto the arm; pod bases
    are rigid PETG carrying a dovetail slot. Removes the per-glasses SNAP_GAP
    tuning loop, so no fit-test print is needed before the final parts.
    Two bugs found and fixed while validating, both silent:
    - rotate([0,90,0]) flips the extruded profile's height axis, which buried
    the dovetail rail inside the ring body. The joint did not exist.
    - ring nubs sat tangent to the cavity wall, leaving a knife edge and a
    non-manifold mesh. Supersede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
    [FINAL_petg_plate.stl, FINAL_tpu_rings.stl, final_frontboard_base.stl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]
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2026-08-29 Support a push button as the manual trigger, and make it the default
    A button is deterministic where capacitive touch is not: touchRead has no
    fixed threshold, and the reading moves with humidity, with how the pad is
    glued in, and with proximity to the wearer's head. It therefore has to be
    tuned on the assembled, worn device and drifts afterwards. For a demo that
    certainty is worth more than avoiding a hole in a lid.
    firmware: rename touchTriggered() to manualTriggered() and branch on
    USE_PUSH_BUTTON. Button path uses INPUT_PULLUP and reads LOW when pressed,
    so a bare button to GND is the whole circuit with no external resistor.
    PIN_TOUCH_PAD becomes PIN_TRIGGER since it is no longer touch-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
    [FINAL_petg_plate.stl, FINAL_petg_plate_HEADERS.stl, final_frontboard_lid.stl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]
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2026-08-30 Add hardware self-test firmware
    Flashing selftest.cpp exercises each subsystem separately and prints a
    pass/fail table, so a failure identifies one component instead of leaving
    six candidates. Tests run in dependency order and the summary says to fix
    the first failure first, since PSRAM failing makes the camera fail too.
    Covers: PSRAM presence, camera init, a real frame capture with a size
    sanity check, button idle state plus an interactive press test, a 440Hz
    tone generated directly over I2S, WiFi association, and an HTTP GET to the
    server's /health endpoint. None of it calls the vision API.
    The tone is generated rather than decoded from MP3 so a silent speaker
    points at the amp or its wi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
    [selftest.cpp]
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2026-08-30 Make touch-pad polarity configurable and add a calibration routine
    touchRead()'s direction is not consistent across the ESP32 family: on the
    original ESP32 the reading falls when touched, on the ESP32-S3 the touch
    peripheral is a different design and it rises. The firmware hard-coded the
    falling-edge comparison, so on this board the pad would either fire
    constantly or never fire, with identical-looking wiring either way.
    Adds TOUCH_ACTIVE_HIGH alongside TOUCH_THRESHOLD in pins.h, and replaces
    the selftest's skipped touch branch with a calibration routine that
    measures an untouched baseline, streams readings while the pad is held,
    then prints which polarity to set and a suggested threshold.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
    [main.cpp, pins.h, selftest.cpp]
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2026-09-04 CAD: cut the lid for the touch pad, and fix a dovetail that never gripped
    The lid was still cut for a push button. Replace the plunger hole with a
    recess for the capacitive pad that was actually built, and flip
    USE_PUSH_BUTTON to match (the selftest only reaches its touch-calibration
    branch when that is 0).
    The pad is a 9 x 20mm stadium rather than a disc. The lid's outer face is
    only 10.2mm across, and that is the axis running into the scalp that the
    two-pod split exists to keep small, so a real coin cannot be fitted without
    undoing the ergonomics. Capacitance follows area, not diameter, so the
    stadium gives roughly three times the area of a 9mm disc while staying
    inside the width availabl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
    [FINAL_petg_plate.stl, FINAL_petg_plate_HEADERS.stl, FINAL_tpu_rings.stl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]
2026-09-04 CAD: print the lids rib-up, as their own comment already said
    The plate comment read "lids flipped rib-side-up so they sit flat with no
    supports", but the rotate([180,0,0]) under it did the opposite: rib down.
    That lifts the lid plate 1mm off the bed and leaves its entire perimeter
    overhanging the rib by about 1.9mm with nothing beneath it, so the edges
    droop and the lid no longer seats squarely in the base.
    Dropping the rotation puts the flat outer face on the bed, which also prints
    the pad recess and camera hole as clean top-surface features and gives the
    touch pad a flat face to bond to.
    Claude-Session: https://claude.ai/code/session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
    [FINAL_petg_plate.stl, FINAL_petg_plate_HEADERS.stl, vocalens_ring.scad]
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2026-09-04 CAD: tighten the ring opening and cut the slack out of both pods
    Ring: the opening drops from 7.0 x 3.2 to 6.0 x 2.6. This part grips by
    stretching, so undersizing is the safe direction to be wrong in — a tight
    ring can be forced on, a loose one cannot be fixed at all.
    Pods: FB_GAP and the two trailing slack constants were set generously while
    the internal layout was still moving, and were never revisited once it was
    fixed. Front pod 48.2 -> 41.7mm, rear 57.2 -> 55.2mm. The slack is now the
    minimum that still lets a wire turn a corner.
    Nothing else shrinks. Both pods' remaining dimensions are the components
    themselves plus 3.2mm of wall, and the rear pod's 31mm outward bulk is the
    28mm s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
    [FINAL_petg_plate.stl, FINAL_petg_plate_HEADERS.stl, FINAL_tpu_rings.stl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]
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2026-09-04 CAD: give the wiring room, and stop the rear pod ignoring fitted headers
    Two problems, both about connector stack rather than the wire itself.
    HEADERS_FITTED only ever applied to the XIAO. The rear pod derived its
    vertical extent from the amp's bare thickness no matter what, so the headers
    variant of the rear pod was byte-identical to the plain one and would not
    have closed over an amp with pins and a jumper socket on it. The amp now has
    its own AMP_HEADERS_FITTED, since which of the two boards has headers is
    independent — you might plug into one and solder flat to the other.
    Neither pod allowed anything above its tallest component. A jumper socket
    leaves along the pin axis, which is the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
    [FINAL_petg_plate.stl, FINAL_petg_plate_HEADERS.stl, final_frontboard_base.stl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]
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2026-09-04 CAD: split the ring into a C so it snaps on instead of threading on
    A closed collar has to slide the full length of the temple arm to reach its
    position, past the hinge at one end or the bend over the ear at the other.
    On some frames neither clears, and there is no way to find that out except
    on the actual glasses. A C presses on wherever it is wanted, and it can be
    made far tighter because the arm spreads the lips going in — that spread is
    where the grip comes from.
    The mouth faces the head, and the side is chosen rather than arbitrary. It
    is opposite the dovetail rail, so the lips of the C are the thin side walls
    that are meant to flex; splitting the rail side would hinge the joint itse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
    [FINAL_tpu_rings.stl, final_temple_ring.stl, vocalens_ring.scad]
2026-09-04 Revert the split ring; tighten the closed ring instead
    Back to a closed collar that threads onto the arm and grips by hoop tension,
    per the original design intent. The C-clip is removed entirely, along with
    its mouth and lead-in parameters.
    With the loop closed the opening can be driven harder, since the whole
    perimeter is in tension rather than two lips being sprung apart:
    RING_IN_VERT 6.0 -> 5.0 and RING_IN_OUT 2.6 -> 2.2, against a typical arm of
    roughly 8-9 x 4-5mm.
    Verified: the inner wall probes solid at the centre where the mouth used to
    be, so the loop really is closed; cavity, outer wall and rail all correct;
    watertight; rail/slot interference unchanged at 0.033 cm3. The PETG plat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
    [FINAL_tpu_rings.stl, final_temple_ring.stl, vocalens_ring.scad]
2026-09-04 Make the flat-wired amp the default build
    AMP_HEADERS_FITTED now defaults to false, so the standard render is the slim
    rear pod. The 10mm a jumper socket costs sits entirely on the axis facing the
    wearer's head, which is the axis the whole two-pod split exists to protect,
    so paying it by default was the wrong way round.
    This is a commitment about how the amp is wired, not a rendering preference:
    a socketed amp does not fit the default pod. The socketed geometry stays
    available as FINAL_petg_plate_AMPSOCKETS.stl and via
    -D AMP_HEADERS_FITTED=true, and the source says so at the flag.
    Dropped the XIAOSOCKETS_AMPFLAT plate, which is now just the default, and its
    two loose rear-pod parts.
    Prin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
    [FINAL_petg_plate.stl, FINAL_petg_plate_AMPSOCKETS.stl, FINAL_petg_plate_HEADERS.stl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]
2026-09-04 Fix the ring size: 5.0 x 2.2 could not be fitted to a real arm
    The opening was driven down on the principle that undersizing is the safe
    direction. The direction was right and the magnitude was not: 2.2mm onto a
    roughly 5mm arm is about 120% strain, where TPU stops behaving like a press
    fit. It either will not go on, or goes on so far stretched that it takes a
    permanent set and ends up gripping worse than a milder fit would have. The
    rule needed a floor, and now has one — target 75-85% of the arm's measured
    section, which is roughly 20-30% strain.
    Default opening is now 7.5 x 3.4mm. Rather than guess a second time,
    temple_ring() takes its opening as arguments and a new tpu_ladder part pri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
    [FINAL_tpu_rings.stl, FINAL_tpu_rings_LADDER.stl, final_temple_ring.stl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]
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2026-09-06 Open the pod cavities — every pod was a sealed box
    The cavity was cut out + EPS deep from a floor at z = WALL, against a top face
    at out + 2*WALL. That stops 1.59mm short, so all four pods were closed shells:
    no way to put the electronics in, and nowhere for the lid's rib to drop. The
    comment directly above the cut already said "open at the top (+Z)"; the code
    did not do it.
    It survived everything: correct from outside in a render, watertight on
    export, correct external dimensions, and it mated with the ring normally. A
    sealed void is perfectly manifold, so no mesh check can see it. Found by
    probing down the middle of the solid, which is now how cavities get verified
    here rather than by t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
    [FINAL_petg_plate.stl, FINAL_petg_plate_AMPSOCKETS.stl, FINAL_petg_plate_HEADERS.stl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]
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2026-09-07 Guard the pad recess depth, and allow a widened front pod for a large coin
    A 20c coin is 28.52mm across and 2.5mm thick. The front lid is 20.5mm wide
    and 1.6mm thick, so the coin neither fits the face nor can be recessed into
    it. Two changes so this fails visibly rather than silently.
    PAD_DEPTH is now clamped to leave 0.6mm of lid beneath the pocket. Asking for
    a 2.5mm recess in a 1.6mm plate previously cut straight through and turned the
    pocket into a hole the pad would fall out of, while still exporting watertight.
    FB_VERT_MIN widens the front pod past what the components need, so the lid can
    carry a larger pad. It is 0 by default. With FB_VERT_MIN=29 the front lid is
    30.5mm wide and tak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
    [FINAL_petg_plate.stl, FINAL_petg_plate_AMPSOCKETS.stl, FINAL_petg_plate_HEADERS_20c.stl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]
2026-09-11 Pods to opposite temples: fit corrections, forward camera, cable sleeve
    Five changes, all from handling the printed parts.
    The dovetail could not be assembled, so DT_SLOT_EXTRA widens the slot by
    0.5mm — the slot only, since the rail's size is also what grips and shrinking
    that would loosen the joint twice. The joint goes from 0.15mm interference to
    0.35mm clearance. That is acceptable rather than a regression: the taper is
    what makes it captive, and a head wider than its neck cannot lift off however
    freely it slides.
    Pod sizes gain named corrections rather than edits to the formulas, so it
    stays obvious which numbers are components and which are somebody's
    measurement. RA_EXTRA_OUT = 15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
    [FINAL_petg_plate.stl, FINAL_petg_plate_AMPSOCKETS.stl, FINAL_petg_plate_HEADERS.stl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]
2026-09-11 Size the camera pod around the 20c coin, and widen it as asked
    The pad was still 18mm wide on a lid that had grown to 23.5mm, so the coin
    did not fit — it needs 28.52mm, and it is 2.5mm thick against a 1.6mm lid,
    which no width would have fixed on its own.
    Two changes. LID_T goes to 3.2 so the coin can recess fully and still leave
    0.7mm of lid beneath it; a recess as deep as its plate is a hole the pad
    falls through. FB_VERT_MIN goes to 28 so the lid reaches 32.5mm wide, and
    with the extra width asked for the pod lands at 34.2mm — the same width as
    the audio pod, which also makes the two temples read as a matched pair
    rather than two unrelated objects.
    PAD_L is set equal to PAD_W so th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
    [FINAL_petg_plate.stl, FINAL_petg_plate_AMPSOCKETS.stl, FINAL_petg_plate_HEADERS.stl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]
2026-09-11 Enlarge the cable pass-throughs and drop the redundant front slot
    The slots were 6 x 4mm, which the five-wire bundle (~3.8mm) only just passed,
    and which the sleeve that has to butt against them (6.6 x 5.4mm outer) could
    not reach at all. A sleeve that stops short of the pod leaves a bare gap at
    each end — exactly where the wires are most visible and most likely to be
    snagged. Now 9 x 6mm, so the sleeve seats flush against the wall.
    Stadium-shaped rather than a square cut. Wire crossing a sharp corner under
    repeated head movement is how insulation chafes through, and this cable will
    move every time the wearer turns their head.
    The camera pod loses its front slot. That wall is the lens ap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
    [FINAL_petg_plate.stl, FINAL_petg_plate_AMPSOCKETS.stl, FINAL_petg_plate_HEADERS.stl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]
2026-09-11 Replace the split cable channel with a closed tube
    The channel had an open mouth the bundle pressed into. It turned five loose
    wires into one tidy line, but you could see straight down onto them the whole
    way — that is tidying, not concealing, and it does not do the job it was added
    for.
    This is a sealed tube: no line of sight to the wires anywhere along the run.
    Verified by probing the wall right round the section — above, below and both
    sides of the bore are all solid, and the bore itself runs open end to end.
    A closed tube is only possible because the bundle can be threaded, and only in
    one direction. The camera-pod end carries Dupont sockets 5.64mm across the
    diagonal, which will n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
    [FINAL_tpu_sleeves.stl, FINAL_tpu_tubes.stl, final_cable_sleeve.stl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]
2026-09-11 Retain the cable tube in a socket on each pod
    The tube butted against a hole and nothing held it, so any tug on the cord
    slid it back and bared the wire at the two points where bare wire looks worst.
    Each pod now carries a short socket boss on its rear end wall, bored 0.3mm
    under the tube's outside diameter so the soft TPU squeezes into the rigid PETG
    — the same joint principle as the ring and rail, where the tolerance is
    absorbed by the soft part.
    Not a dovetail, though that was the obvious thing to reach for. A dovetail
    resists lift-off perpendicular to its slide axis, and the load here is axial
    pull-out straight along the tube, which a dovetail does not oppose at all.
    The boss is adde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
    [FINAL_petg_plate.stl, FINAL_petg_plate_AMPSOCKETS.stl, FINAL_petg_plate_HEADERS.stl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]
2026-09-11 Print the cable tube pre-curved, 430mm total
    A straight tube forced round a head is a spring. Every millimetre of it stores
    energy and pushes back, and it has only two things to push against — the two
    pods, which are held on by nothing but friction against TPU rings. Given a
    demo's worth of head movement it would walk them off. Curved to the shape it
    is worn in, it sits there instead.
    R = 95mm, roughly the back of a head. Constant radius rather than a real head
    profile: the temple runs are straighter than the back is, but TPU straightens
    far more easily than it bends, so erring toward the tighter curve leaves the
    easy correction rather than the hard one.
    430mm total as 2 x 215mm crescent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
    [FINAL_tpu_tubes.stl, FINAL_tpu_tubes_1PIECE.stl, final_cable_tube.stl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]
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
